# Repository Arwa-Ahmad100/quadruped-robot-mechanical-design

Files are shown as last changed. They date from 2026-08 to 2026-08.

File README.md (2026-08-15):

# 12-DOF Quadruped Robot
### Mechanical Design · Engineering Analysis · Parametric CAD · Digital Manufacturing

A complete mechanical design study of a **12-DOF quadruped robotic platform**, developed from the initial engineering concept through mechanical analysis, CAD implementation, and manufacturing-ready STL export.

The project focuses on the fundamental mechanical principles required for a quadruped robot to stand and support future walking implementation, including chassis architecture, articulated leg design, degrees of freedom, actuator sizing, joint torque estimation, stability, center-of-gravity considerations, gait selection, and expected mechanical challenges.

The mechanical concept was transformed into a complete editable CAD assembly using **Autodesk Fusion**, then prepared for manufacturing through individual STL exports and documented in this repository.

<p align="center">
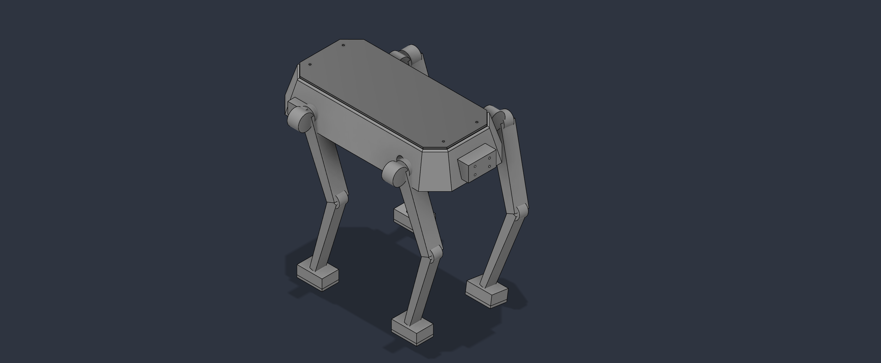
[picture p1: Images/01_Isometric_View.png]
  
</p>

---

## Project Overview

The goal of this project is to develop a mechanically understandable, modular, and manufacturable quadruped robot rather than an unnecessarily complex robotic platform.

The final design consists of:

- 4 articulated legs
- 3 rotational Degrees of Freedom per leg
- **12 DOF total**
- Modular leg architecture
- Central structural chassis
- Low and centralized battery tray
- Removable top cover
- M3 fastening features
- Front sensor mounting interface
- Replaceable foot pads
- Separate manufacturing parts
- Editable Autodesk Fusion source model
- Individual STL files for fabrication

### Design Philosophy

The project prioritizes:

**Modularity · Stability · Manufacturability · Maintainability · Mechanical Simplicity · Sensor Flexibility**

---

# 1. Mechanical Architecture

The robot uses a four-legged quadruped configuration built around a central chassis.

The chassis provides the primary structural platform for:

- Leg attachment
- Battery placement
- Future control electronics
- Power electronics
- Sensor integration
- Future experimental payloads

The design intentionally avoids decorative animal features such as a head or tail.

Instead, the robot is treated as a **functional mobile robotic platform** whose geometry is driven primarily by mechanical requirements.

---

# 2. Chassis Design

The chassis was designed as a compact structural frame with approximately:

| Parameter | Approximate Value |
|---|---:|
| Length | 310 mm |
| Width | 160 mm |
| Overall chassis height | ≈ 75 mm |
| Structural wall | ≈ 4 mm |
| M3 clearance holes | 3.4 mm |

The chassis incorporates:

- Main structural frame
- Internal electronics space
- Central battery tray
- Removable top cover
- Four leg interfaces
- Front sensor mounting interface
- M3 fastening locations

The geometry uses a restrained angular profile rather than a simple solid rectangular box, providing a more functional robotic structure while keeping the CAD reliable and manufacturable.

---

# 3. Leg Design

The robot contains four mechanically similar leg modules.

Each leg contains:

```text
Hip Roll
   │
Hip Pitch
   │
Upper Link
   │
Knee
   │
Lower Link
   │
Foot
   │
Foot Pad
```

Approximate dimensions:

| Component | Approximate Dimension |
|---|---:|
| Upper Link | 118 mm |
| Lower Link | 128 mm |
| Foot | 45 × 30 × 16 mm |

The upper and lower links were designed as structural mechanical members rather than simple rods.

The modular leg architecture also allows repeated components to be manufactured from the same STL geometry.

---

# 4. Degrees of Freedom

Each leg contains **three rotational Degrees of Freedom**.

## Hip Roll

Provides lateral movement of the leg.

This joint represents:

**Abduction / Adduction**

and allows the leg to move away from or toward the robot body.

## Hip Pitch

Provides forward and backward motion of the upper leg.

This joint contributes significantly to:

- Step length
- Forward motion
- Body positioning

## Knee Pitch

Controls bending and extension of the lower leg.

This joint is responsible for:

- Foot lifting
- Leg extension
- Ground clearance
- Standing-height adjustment

Therefore:

```text
3 DOF per leg × 4 legs = 12 DOF
```

### Final Architecture

**12-DOF Quadruped Robot**

---

# 5. Preliminary Joint Motion Ranges

The mechanical architecture was developed around approximate revolute-joint ranges suitable for a preliminary quadruped design.

| Joint | Preliminary Motion Range |
|---|---:|
| Hip Roll | -35° to +35° |
| Hip Pitch | -70° to +90° |
| Knee Pitch | 0° to 130° |

These limits provide a starting point for standing and walking studies while reducing the risk of unrealistic joint motion.

Final limits should be validated after integrating the exact physical actuators.

---

# 6. Preliminary Actuator Selection

Quadruped joints require controlled angular positioning.

For this reason, a **servo actuator** is more appropriate for the preliminary design than a continuously rotating DC motor.

The proposed actuator category is:

## High-Torque Digital Metal-Gear Servo

Preliminary target requirements:

| Parameter | Target |
|---|---|
| Actuator type | Digital Servo |
| Gear system | Metal Gear |
| Angular position control | Required |
| Preliminary torque target | ≥ 35 kg·cm |
| Preferred design range | 35–40 kg·cm |
| Quantity | 12 |

Using a common actuator class across the twelve joints can simplify:

- Mechanical mounting
- Electrical architecture
- Control software
- Maintenance
- Spare-part management
- Future replacement

> The actuator specification is preliminary. Final servo selection requires physical testing, power analysis, dynamic load analysis, and exact servo mounting dimensions.

---

# 7. Preliminary Joint Torque Calculation

A preliminary torque calculation was performed for the **Knee Pitch joint**.

The basic relationship is:

```text
τ = F × r
```

where:

```text
τ = Joint torque
F = Applied force
r = Distance from the rotational axis
```

## 7.1 Robot Weight

The CAD model produced a conservative solid-body mass estimate of approximately:

```text
m = 3.71 kg
```

Using:

```text
g = 9.81 m/s²
```

the gravitational force is:

```text
W = m × g

W = 3.71 × 9.81

W ≈ 36.4 N
```

The **3.71 kg value is a conservative CAD estimate**, not an expected final printed robot mass.

Real FDM components are normally manufactured using partial infill and would typically weigh less than equivalent fully solid CAD bodies.

---

## 7.2 Supporting-Leg Load

For the proposed crawl gait, one leg may be lifted while the other three support the robot.

A simplified equal-load assumption gives:

```text
F = 36.4 / 3

F ≈ 12.13 N
```

Therefore, each supporting leg carries approximately:

```text
12.13 N
```

under this simplified quasi-static condition.

---

## 7.3 Knee Torque

The lower-link length is approximately:

```text
r = 128 mm
r = 0.128 m
```

Therefore:

```text
τ = F × r

τ = 12.13 × 0.128

τ ≈ 1.55 N·m
```

This represents a simplified static estimate.

---

## 7.4 Safety Factor

A preliminary safety factor of:

```text
SF = 2
```

is applied.

Therefore:

```text
τ_design = 1.55 × 2

τ_design ≈ 3.11 N·m
```

Converting approximately to the unit commonly used for robotic servos:

```text
3.11 N·m ≈ 31.7 kg·cm
```

A reasonable preliminary actuator target is therefore:

## ≥ 35 kg·cm

This provides additional margin for effects that are not represented in the simplified static calculation, including:

- Link self-weight
- Acceleration
- Joint friction
- Foot-ground impact
- Manufacturing tolerances
- Uneven load distribution
- Dynamic motion

---

# 8. Stability & Center of Gravity

Static stability is a critical consideration in quadruped design.

The robot is most stable when the projected center of gravity remains inside the polygon created by the supporting feet.

Several design decisions were made to improve stability.

## Low Battery Placement

The battery tray is located close to the geometric center of the chassis and as low as reasonably possible.

This helps:

- Lower the center of gravity
- Reduce tipping tendency
- Improve weight distribution
- Improve standing stability

## Centralized Mass

Heavy components should remain near the center of the chassis whenever possible.

Large masses mounted high or far from the robot center could shift the center of gravity and reduce stability.

## Four-Leg Support

When all four feet contact the ground, they create a relatively large support polygon.

The projected center of gravity should remain inside this area.

## Three-Leg Support

During crawl walking, one foot is lifted.

The remaining three feet create a triangular support region.

Before lifting a leg, the body should shift sufficiently so that the projected center of gravity remains inside this triangle.

This approach produces a **quasi-static walking strategy** that prioritizes stability rather than speed.

---

# 9. Proposed Walking Method

The initial walking strategy proposed for this platform is:

## Static Crawl Gait

A crawl gait is suitable for an early quadruped prototype because three legs remain in contact with the ground while the fourth leg moves.

One possible stepping sequence is:

```text
Front Left
     ↓
Rear Right
     ↓
Front Right
     ↓
Rear Left
     ↓
Repeat
```

For each step:

1. Three feet remain on the ground.
2. The body weight shifts toward the supporting legs.
3. The projected center of gravity is kept inside the support triangle.
4. One leg is lifted.
5. The leg moves toward its next position.
6. The foot returns to the ground.
7. The sequence continues with the next leg.

The initial goal is therefore:

**Stable walking before fast walking.**

Once a physical prototype achieves reliable crawl locomotion, a more dynamic gait such as **trot** could be investigated.

---

# 10. Expected Mechanical Challenges

Several mechanical challenges are expected during physical implementation.

## Servo Torque & Heating

Operating actuators near their maximum torque for extended periods may cause:

- Heating
- Reduced performance
- Increased power consumption
- Servo stall

The preliminary torque calculation therefore includes additional design margin.

## Joint Backlash

Mechanical clearance inside servo gear trains can introduce backlash.

This can reduce:

- Joint positioning accuracy
- Foot-position accuracy
- Walking repeatability

## Structural Flexibility

Long FDM-printed links may bend under load.

Structural performance will depend on:

- Material
- Infill
- Wall thickness
- Layer orientation
- Printing parameters
- Joint loads

## Foot Slipping

Rigid printed feet may provide insufficient friction on smooth surfaces.

The separate `Foot_Pad` component allows future use of a higher-friction material such as TPU or rubber.

## Manufacturing Tolerances

FDM printing introduces dimensional variation.

Critical areas include:

- M3 holes
- Joint interfaces
- Mechanical clearances
- Actuator mounting regions
- Cover alignment

## Joint Collision

Joint limits must prevent:

- Link-to-chassis collisions
- Leg self-collision
- Excessive joint rotation

## Cable Routing

Twelve actuators require significant wiring.

The wiring should remain protected from:

- Moving joints
- Ground contact
- Sharp edges
- External snagging

Cable routing can be refined further after the final actuator and electronics layout are selected.

## Weight Distribution

Battery, electronics, sensors, and payloads can shift the robot's center of gravity.

Future hardware integration should therefore preserve centralized mass distribution whenever possible.

---

# 11. Parametric CAD Implementation

The mechanical concept was transformed into a complete 3D CAD assembly using:

## Autodesk Fusion

Autodesk Fusion was used as the project's feature-based mechanical CAD environment.

The design includes:

- Sketch-based geometry
- Dimensioned features
- Separate components
- Assembly structure
- Revolute joints
- Editable design timeline
- Manufacturing mesh export
- Mass-property inspection
- Interference inspection

The editable Fusion archive is included with the project.

---

# 12. CAD Component Architecture

The project was organized around a modular component structure:

```text
Quadruped Robot
│
├── Chassis
│   ├── Main Frame
│   ├── Battery Tray
│   └── Top Cover
│
├── Leg Module ×4
│   ├── Hip Roll
│   ├── Hip Pitch
│   ├── Upper Link
│   ├── Knee
│   ├── Lower Link
│   ├── Foot
│   └── Foot Pad
│
└── 12-DOF Mechanical Architecture
```

The leg architecture is reused across all four corners rather than designing four unrelated legs.

This improves:

- Modularity
- Symmetry
- Maintainability
- Manufacturing consistency
- Design reuse

---

# 13. Removable Top Cover

The robot includes an independent top cover following the chassis geometry.

The cover includes four M3 clearance locations.

The removable design provides:

- Electronics access
- Easier maintenance
- Battery/electronics inspection
- Faster future modification

The exported manufacturing geometry is provided as:

```text
Top_Cover.stl
```

---

# 14. Battery Integration

The battery tray is designed as an independent mechanical component positioned low and centrally inside the chassis.

The design strategy reserves the region above the battery for future systems such as:

- Microcontroller
- Power electronics
- Motor-control electronics
- Custom PCB
- Communication hardware

This arrangement helps maintain a lower center of gravity.

---

# 15. Sensor Integration

The chassis includes a front mechanical mounting interface for future perception hardware.

Potential modules include:

- Distance sensors
- ToF sensors
- Camera
- Depth camera
- Stereo camera
- Compact LiDAR
- Embedded vision systems

The sensors themselves were intentionally not modeled.

Instead, the mechanical platform provides an interface for future integration without requiring redesign of the complete chassis.

---

# 16. Foot Design

Each leg terminates in two components:

```text
Structural Foot
      +
Replaceable Foot Pad
```

The structural foot provides the main load path.

The separate foot pad allows future experimentation with different ground-contact materials.

A future physical prototype could manufacture the pad using:

- TPU
- Rubber-like material
- High-friction polymer

This provides a simple method for improving ground traction without redesigning the entire leg.

---

# 17. Manufacturing Strategy

The robot is designed with FDM additive manufacturing in mind.

The mechanical design emphasizes:

- Separate printable components
- Moderate wall thickness
- Accessible fasteners
- Replaceable parts
- Simple structural geometry
- Limited unnecessary decorative features
- Practical component assembly

Instead of exporting the complete robot as one fused mesh, the unique mechanical components are exported separately.

This improves:

- Print orientation
- Component replacement
- Repairability
- Manufacturing flexibility
- Iterative prototyping

---

# 18. STL Manufacturing Files

The final design contains **10 unique manufacturing geometries**.

| STL File | Required Quantity | Function |
|---|---:|---|
| `Main_Frame.stl` | 1 | Primary structural chassis |
| `Battery_Tray.stl` | 1 | Low central battery support |
| `Top_Cover.stl` | 1 | Removable chassis cover |
| `Hip_Roll.stl` | 4 | Lateral hip joint structure |
| `Hip_Pitch.stl` | 4 | Forward/backward hip joint structure |
| `Upper_Link.stl` | 4 | Upper structural leg link |
| `Knee.stl` | 4 | Knee joint structure |
| `Lower_Link.stl` | 4 | Lower structural leg link |
| `Foot.stl` | 4 | Structural ground-contact foot |
| `Foot_Pad.stl` | 4 | Replaceable contact pad |

### Manufacturing Summary

```text
10 unique STL geometries
31 physical mechanical components
```

The reusable leg architecture means repeated parts only require one unique STL file.

All STL files are located in:

```text
STL/
```

---

# 19. CAD Design Views

## Isometric View

<p align="center">
  
</p>

---

## Front View

<p align="center">
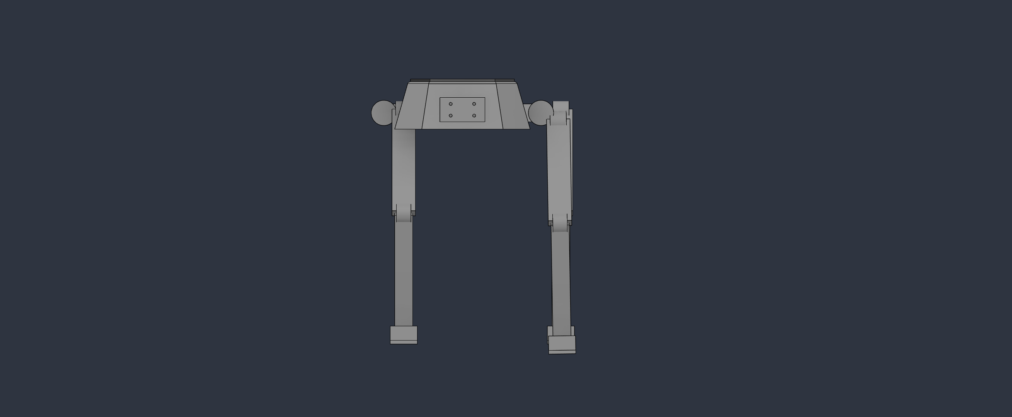
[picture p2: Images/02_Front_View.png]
  
</p>

---

## Side View

<p align="center">
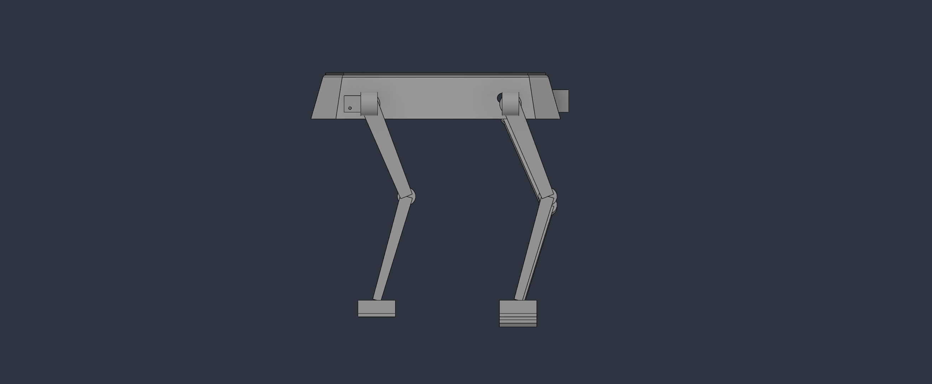
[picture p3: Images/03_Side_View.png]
  
</p>

---

## Top View

<p align="center">
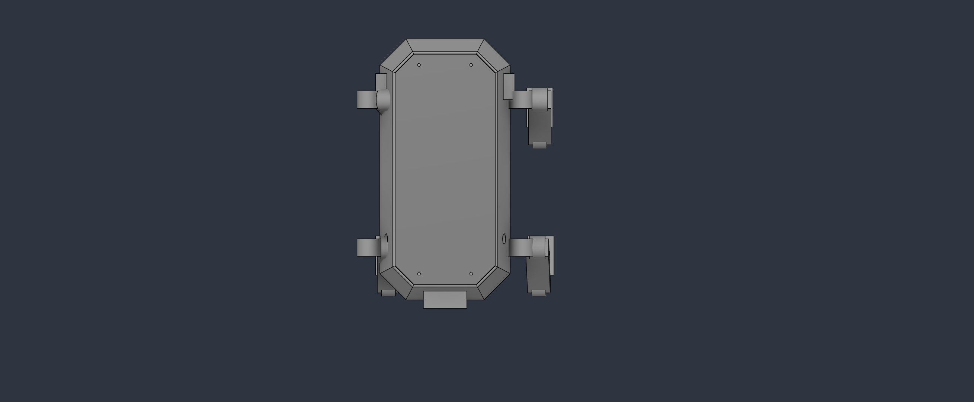
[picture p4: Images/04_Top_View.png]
  
</p>

---

# 20. Editable CAD Design

The complete editable Autodesk Fusion archive is included in:

```text
CAD/Quadruped_Robot_Final_Submission.f3d
```

### Autodesk Fusion Shared Design

[View / Download the Autodesk Fusion Design](https://a360.co/3Sg3Qcz)

Download access is enabled on the shared design.

A copy of the design-link information is also stored in:

```text
Documentation/Design_Link.txt
```

The repository therefore provides:

- Editable `.f3d` source model
- Fusion design history
- Shared browser-accessible design
- Download-enabled Autodesk link
- Individual STL manufacturing files
- CAD visualization images

---

# 21. Tools & Engineering Workflow

## Autodesk Fusion

Autodesk Fusion was used as the primary mechanical CAD environment for:

- Mechanical CAD modeling
- Component creation
- Assembly development
- Revolute-joint definition
- Design refinement
- Mass estimation
- Interference inspection
- STL generation
- Editable design archive

---

## Claude + Autodesk Fusion Integration

Claude was incorporated into the development process through an **AI-assisted CAD workflow connected to Autodesk Fusion**.

The integration supported:

- Repetitive CAD operations
- Component inspection
- Assembly auditing
- Joint verification
- Geometry review
- Dimensional checking
- Interference review
- Iterative CAD refinement
- Design-review assistance

The engineering requirements, mechanical architecture, constraints, acceptance criteria, and final design decisions were reviewed throughout the workflow.

AI assistance was used to accelerate CAD iteration and inspection while maintaining the project's mechanical requirements and design objectives.

---

# 22. Repository Structure

```text
quadruped-robot-mechanical-design/
│
├── CAD/
│   └── Quadruped_Robot_Final_Submission.f3d
│
├── Documentation/
│   └── Design_Link.txt
│
├── Images/
│   ├── 01_Isometric_View.png
│   ├── 02_Front_View.png
│   ├── 03_Side_View.png
│   └── 04_Top_View.png
│
├── STL/
│   ├── Battery_Tray.stl
│   ├── Foot.stl
│   ├── Foot_Pad.stl
│   ├── Hip_Pitch.stl
│   ├── Hip_Roll.stl
│   ├── Knee.stl
│   ├── Lower_Link.stl
│   ├── Main_Frame.stl
│   ├── Top_Cover.stl
│   └── Upper_Link.stl
│
└── README.md
```

---

# 23. Current Limitations

This project represents a **preliminary mechanical engineering design** rather than a production-ready quadruped robot.

Current limitations include:

- The final commercial servo model has not yet been selected and experimentally validated.
- Torque sizing is based on a simplified quasi-static model.
- Dynamic impact loads have not yet been experimentally measured.
- Servo-specific mounting geometry can be refined after exact actuator selection.
- Detailed cable-management geometry can be improved.
- FDM strength and print orientation require physical prototype testing.
- Full multi-leg assembly motion validation remains future work.
- Dynamic walking has not yet been physically implemented.
- Electronics and embedded control hardware are outside the current mechanical CAD scope.

These limitations identify the remaining engineering work required before physical implementation.

---

# 24. Engineering Outcome

This project demonstrates the transition from an initial quadruped concept into an **editable, modular, and manufacturing-oriented mechanical CAD platform**.

The final design emphasizes:

<p align="center">

**MODULARITY · STABILITY · MANUFACTURABILITY**

**MAINTAINABILITY · MECHANICAL SIMPLICITY**

**SENSOR FLEXIBILITY · 12-DOF QUADRUPED LOCOMOTION**

</p>

The project intentionally focuses on strong mechanical fundamentals rather than unnecessary complexity.

The resulting architecture provides a structured foundation for future physical prototyping, actuator integration, embedded control, sensing, and quadruped locomotion.

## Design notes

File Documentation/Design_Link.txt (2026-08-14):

QUADRUPED ROBOT — EDITABLE CAD DESIGN

Autodesk Fusion Share Link:
https://a360.co/3Sg3Qcz

Editable Source File:
../CAD/Quadruped_Robot_Final_Submission.f3d

CAD Software:
Autodesk Fusion

Design Type:
Parametric CAD Quadruped Robot

Notes:
- The Autodesk Fusion link provides access to the latest shared design.
- Download access is enabled.
- The .f3d source file contains the editable Fusion CAD model and design history.
- Individual STL manufacturing files are provided separately in the STL folder.

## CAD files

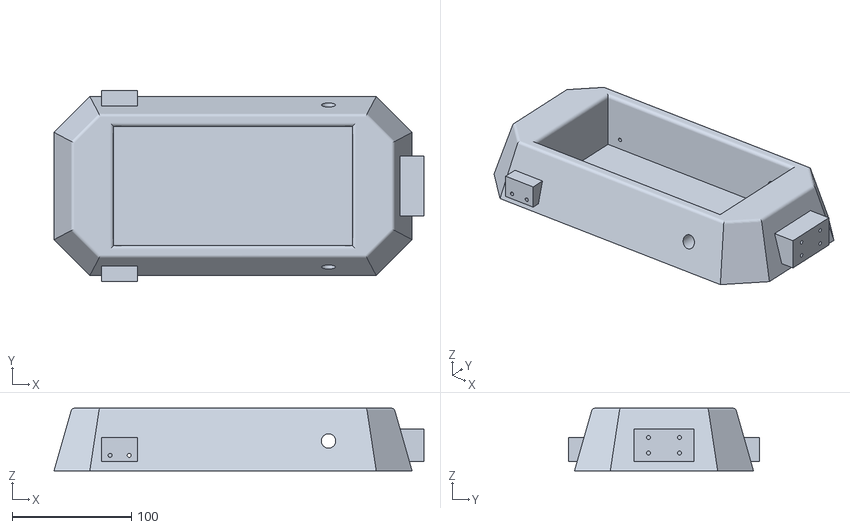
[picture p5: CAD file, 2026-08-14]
STL/Main_Frame.stl
310.0 x 160.0 x 52.5

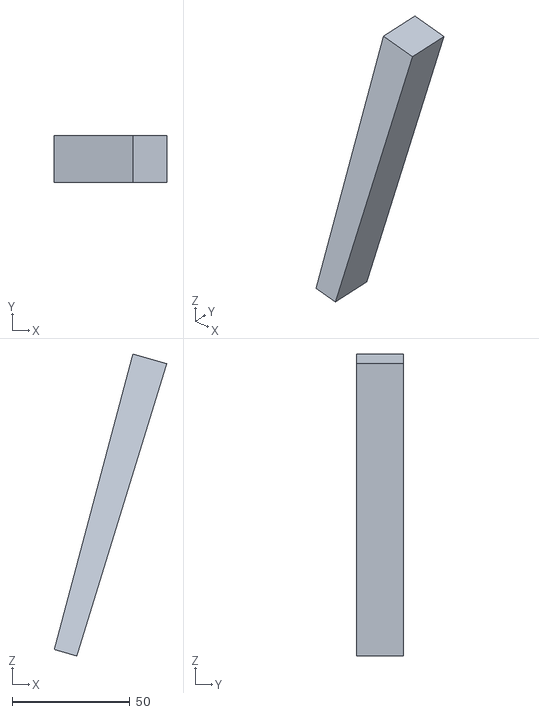
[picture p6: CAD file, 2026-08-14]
STL/Lower_Link.stl
47.8 x 20.0 x 128.4

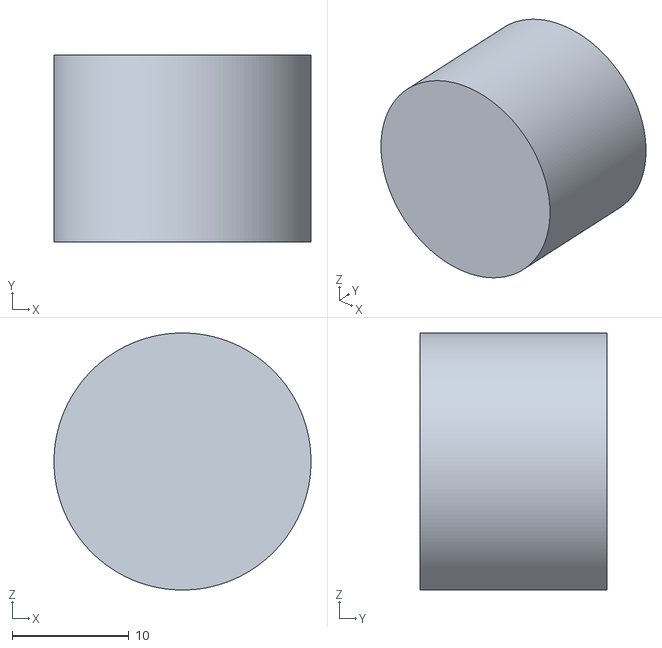
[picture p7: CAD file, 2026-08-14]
STL/Knee.stl
22.0 x 16.0 x 22.0

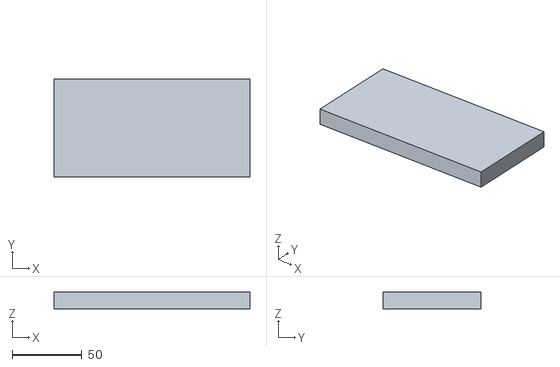
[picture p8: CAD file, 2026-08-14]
STL/Battery_Tray.stl
140.0 x 70.0 x 12.0

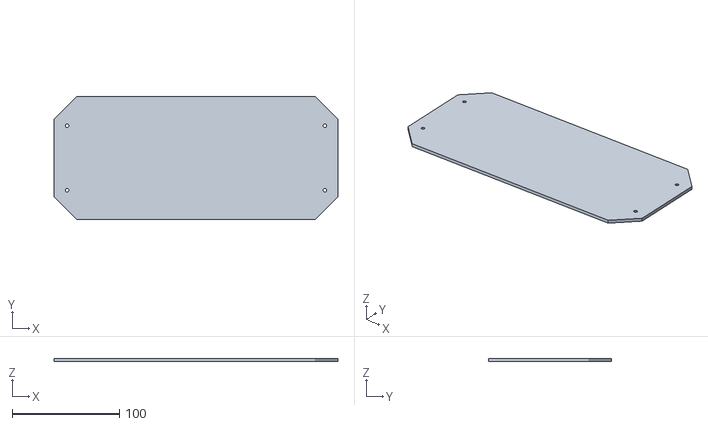
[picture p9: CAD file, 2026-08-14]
STL/Top_Cover.stl
264.4 x 114.9 x 3.00

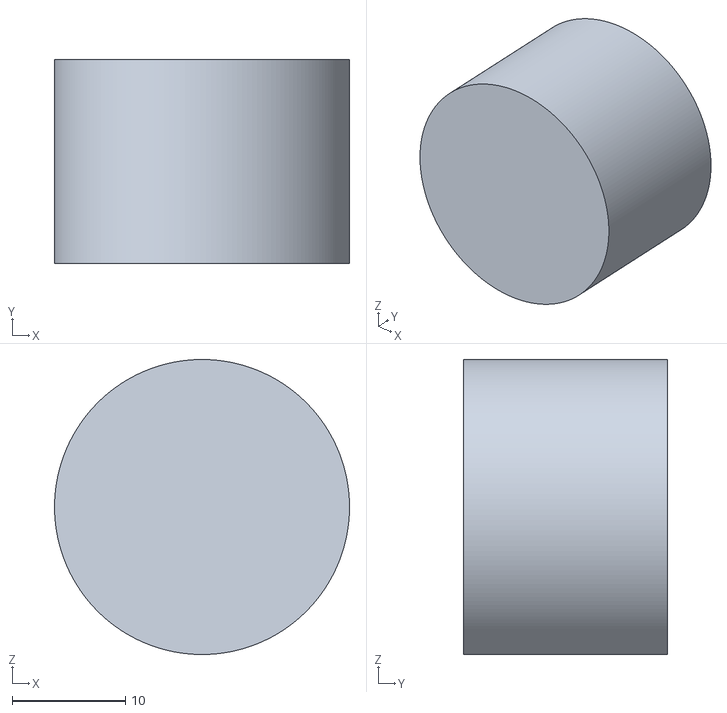
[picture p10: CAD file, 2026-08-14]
STL/Hip_Pitch.stl
26.0 x 18.0 x 26.0

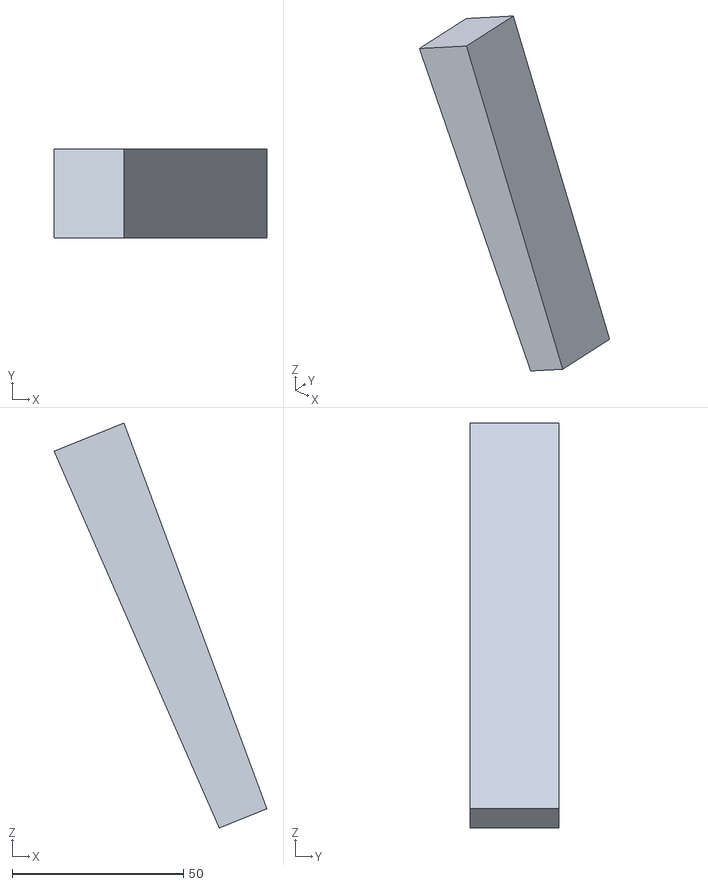
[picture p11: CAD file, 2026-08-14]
STL/Upper_Link.stl
62.1 x 26.0 x 118.2

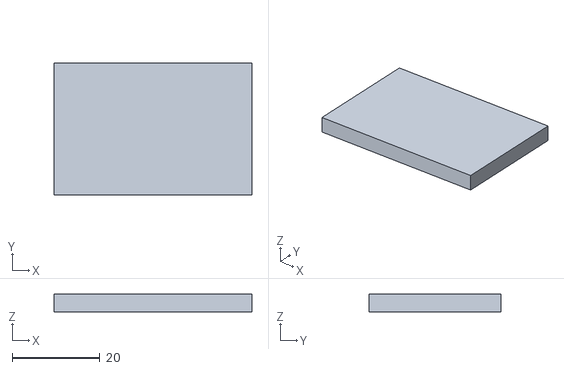
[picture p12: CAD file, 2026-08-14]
STL/Foot_Pad.stl
45.0 x 30.0 x 4.00

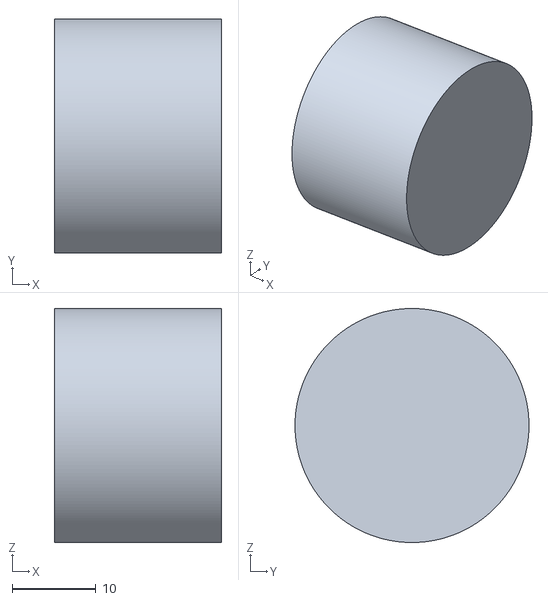
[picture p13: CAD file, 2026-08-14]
STL/Hip_Roll.stl
20.0 x 28.0 x 28.0

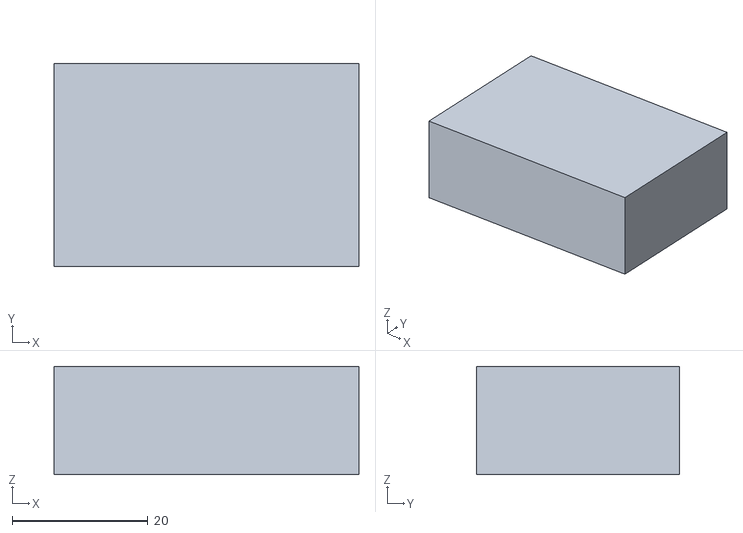
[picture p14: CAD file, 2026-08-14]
STL/Foot.stl
45.0 x 30.0 x 16.0

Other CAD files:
CAD/Quadruped_Robot_Final_Submission.f3d

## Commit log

2026-08-14 Add editable Fusion CAD source
    [Quadruped_Robot_Final_Submission.f3d]
2026-08-14 Add CAD design views
2026-08-14 Add manufacturing STL files
    [Battery_Tray.stl, Foot.stl, Foot_Pad.stl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]
2026-08-15 Revise README for 12-DOF quadruped robot project
    Updated the README to provide a comprehensive overview of the 12-DOF quadruped robot project, including mechanical design, project goals, design philosophy, and detailed sections on architecture, act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
